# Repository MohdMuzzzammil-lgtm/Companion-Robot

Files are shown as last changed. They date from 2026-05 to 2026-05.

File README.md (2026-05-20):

# 🤖 Companion Robot

An AI-powered autonomous two-wheeled robot that uses a **Samsung smartphone as its brain** — no Raspberry Pi, no expensive hardware. Built for under ₹5000.





---

## 📸 Demo

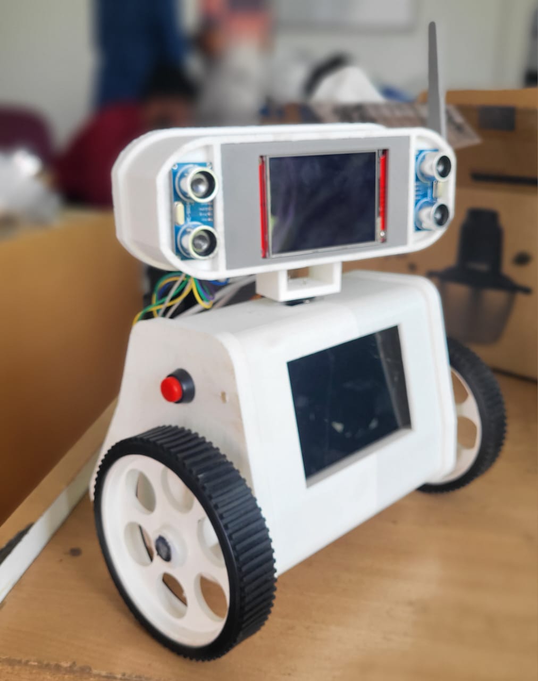
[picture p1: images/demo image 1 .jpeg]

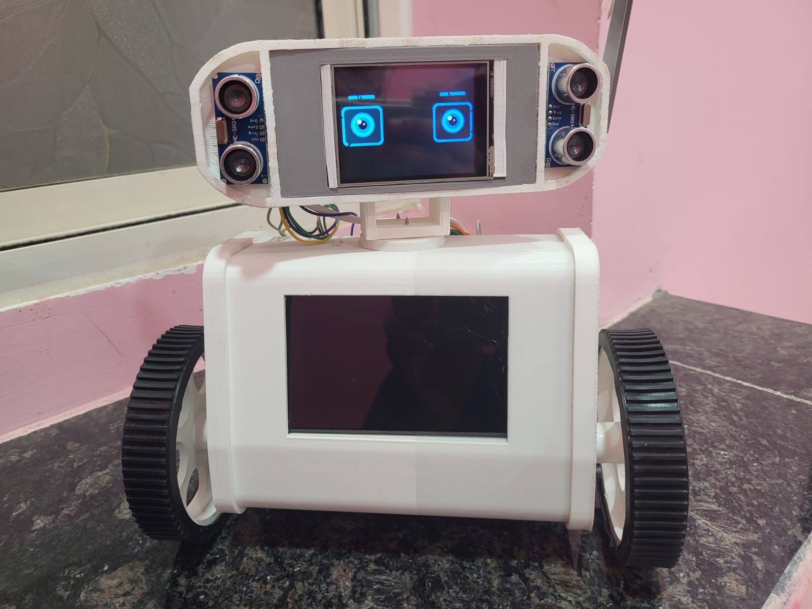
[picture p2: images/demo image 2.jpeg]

Companion Robot
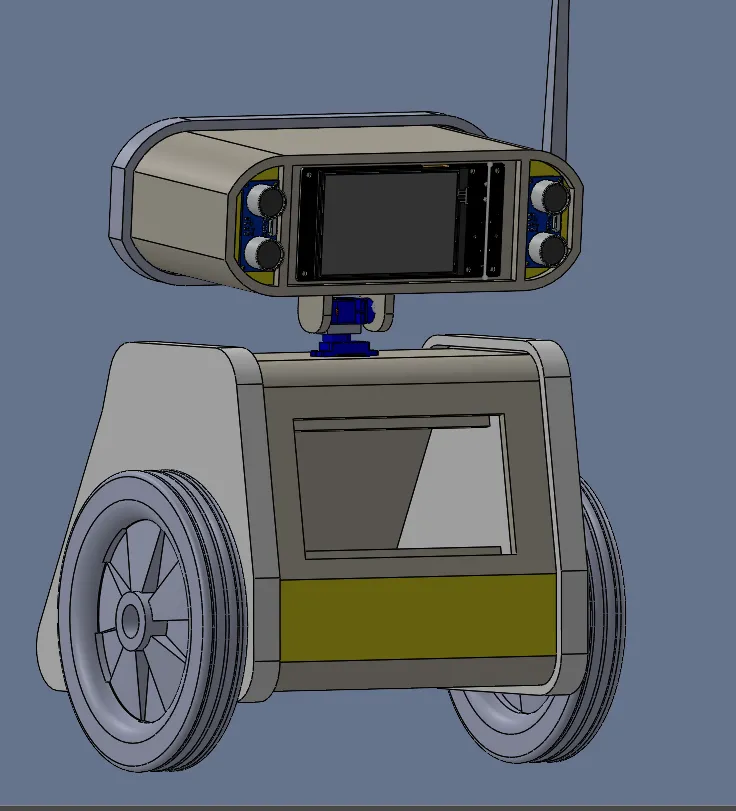
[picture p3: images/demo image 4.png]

---

## ✨ Features

- **Local LLM** — Llama 3.1 via Ollama on laptop GPU, fully offline AI
- **Voice control** — Whisper speech recognition (cloud + local fallback)
- **Animated eyes** — ILI9341 TFT with 5 moods: happy, curious, angry, listening, sleeping
- **Obstacle avoidance** — dual HC-SR04 ultrasonic sensors with pan compensation
- **Human detection** — YOLOv8 on laptop GPU, reacts when it sees a person
- **Expressive antenna** — wiggles when talking, droops when sleeping
- **Gamepad control** — Cosmic Byte Blitz via laptop
- **Touch controller** — HTML joystick interface in phone browser
- **Display mode** — wheels locked for table demos, everything else alive

---

## 🔧 Hardware

| Component | Purpose |
|---|---|
| Samsung S21 FE | AI brain — runs Python + Whisper in Termux |
| ESP32 DevKit v1 (30-pin) | Hardware controller |
| L298N Motor Driver | Controls 2 DC motors |
| 2× Rhino GB37 12V 110RPM | Drive wheels |
| MG996R Servo | Head pan (GPIO 13) |
| SG90 Servo | Antenna wiggle (GPIO 12) |
| 2× HC-SR04 | Obstacle detection |
| ILI9341 2.8" TFT | Animated robot eyes |
| Cosmic Byte Blitz Gamepad | Manual control |
| 2S LiPo 7.4V | Motors + pan servo |
| Power bank 5V | ESP32 + TFT + sensors |

---

## 📌 ESP32 Pin Map

```
GPIO 27 → L298N IN1          GPIO 5  → HC-SR04 Left TRIG
GPIO 26 → L298N IN2          GPIO 34 → HC-SR04 Left ECHO
GPIO 25 → L298N IN3          GPIO 22 → HC-SR04 Right TRIG
GPIO 33 → L298N IN4          GPIO 35 → HC-SR04 Right ECHO
GPIO 13 → MG996R Pan Servo   GPIO 32 → Push Button
GPIO 12 → SG90 Antenna       GPIO 15 → TFT CS
GPIO 23 → TFT MOSI           GPIO 18 → TFT SCK
GPIO 4  → TFT RST            GPIO 2  → TFT DC
```

---

## 🗂️ File Structure

```
companion-robot/
│
├── esp32/
│   └── phonebot_esp32.ino       # ESP32 firmware (Arduino)
│
├── phone/
│   └── robot_brain_v9.py        # Phone brain (Termux Python)
│
├── laptop/
│   ├── phonebot_laptop.py       # Gamepad + YOLOv8 vision
│   └── phonebot_vision.py       # Vision only (older)
│
├── web/
│   ├── phonebot_controller.html # Touch joystick controller
│   └── phonebot_display.html    # Chest status display
│
└── README.md
```

---

## 🚀 Setup

### Prerequisites

**Phone (Termux):**
```bash
pkg install python ffmpeg
pip install requests groq
```

**Laptop:**
```bash
pip install pygame requests ultralytics opencv-python
# Install Ollama: https://ollama.com
ollama pull llama3.1
```

**Arduino IDE** — install these libraries:
- `ESP32Servo`
- `TFT_eSPI`
- `WebServer` (built-in)

### TFT_eSPI User_Setup.h
```cpp
#define ILI9341_DRIVER
#define TFT_MOSI  23
#define TFT_SCLK  18
#define TFT_CS    15
#define TFT_DC     2
#define TFT_RST    4
#define TFT_MISO  -1
#define SPI_FREQUENCY 40000000
```

---

## ⚙️ Configuration

Edit the top of `robot_brain_v9.py` each session:

```python
ESP32_IP   = "X.X.X.X"      # check ESP32 Serial Monitor
LAPTOP_IP  = "X.X.X.X"      # run ipconfig on laptop
GROQ_KEY   = "your_key"      # from console.groq.com (free)
SAFE_DIST  = 40              # obstacle threshold in cm
```

For Ollama to work over WiFi:
```cmd
set OLLAMA_HOST=0.0.0.0:11434
ollama serve
```

---

## 🎮 Startup Checklist

```
1. Turn on phone hotspot (Galaxy S21 / your password)
2. Power ESP32 → note IP from Serial Monitor
3. Connect laptop to hotspot → run ipconfig → note IP
4. Start Ollama: set OLLAMA_HOST=0.0.0.0:11434 && ollama serve
5. Update IPs in robot_brain_v9.py and phonebot_laptop.py
6. Phone Termux:
      termux-wake-lock
      python ~/robot_brain_v9.py
7. Laptop:
      python phonebot_laptop.py
8. Optional touch controller → open in Chrome:
      file:///sdcard/phonebot_controller.html
```

---

## 🗣️ Voice Commands

| Say | Action |
|-----|---|
| *"showcase"* / *"demo"* | Runs table demo routine |
| *"look around"* | Scans environment |
| *"sleep"* / *"goodnight"* | Sleep mode |
| *"wake up"* / *"hello"* | Wake animation |
| *"display mode"* | Lock wheels for table display |
| *"drive mode"* | Unlock wheels |
| *"status"* | Reports AI + STT source |
| Anything else | AI conversation via Llama 3.1 |

---

## 🎮 Gamepad Controls

| Button | Action |
|---|---|
| Left stick | Move |
| Right stick X | Pan head |
| A | Voice mode |
| B | Look around |
| X | Happy mood |
| Y | Toggle vision |
| LB / RB | Speed down / up |
| SELECT | Sleep |
| START | Wake up |

---

## 🌐 ESP32 HTTP API

```
GET /forward         GET /backward        GET /left
GET /right           GET /stop
GET /pan?angle=N     (30–150°)
GET /mood?m=N        (0=happy 1=curious 2=angry 3=listening 4=sleeping)
GET /sensors         returns {"left":N,"right":N,"pan":N}
GET /lookaround      7-angle environment scan
GET /button          returns {"pressed":true/false}
GET /antenna?wiggle=N
GET /displaymode?on=1   lock wheels for table demo
GET /displaymode?on=0   unlock wheels
```

---

## 💡 How It Works

```
[Person speaks] → Phone mic → Whisper STT
                                    ↓
                             Llama 3.1 (Ollama on laptop)
                                    ↓
                    Response → TTS (termux-tts-speak)
                             → ESP32 movement command
                             → Eye mood change

[Camera] → YOLOv8 (laptop) → person detected
                                    ↓
                    Reaction → TTS greeting
                             → Bot turns toward person
                             → Antenna wiggle
```

---

## 🛒 Parts List (India)

| Part | Approx Cost |
|---|---|
| ESP32 DevKit v1 | ₹350 |
| L298N Motor Driver | ₹120 |
| 2× Rhino GB37 Motors | ₹1200 |
| MG996R Servo | ₹200 |
| SG90 Servo | ₹80 |
| 2× HC-SR04 | ₹100 |
| ILI9341 TFT 2.8" | ₹350 |
| 2S LiPo Battery | ₹600 |
| Miscellaneous (wires, standoffs) | ₹300 |
| **Total** | **~₹3300** |

> Samsung S21 FE and laptop not included — reused existing hardware

---

## 📋 Known Issues

- HC-SR04 ECHO pins need `INPUT_PULLUP` (not `INPUT`)
- GPIO 19 conflicts with TFT MISO — Right TRIG moved to GPIO 22
- `termux-tts-speak` must use `Popen` not `run` to avoid timeout
- OTG serial not possible on unrooted Samsung S21 FE
- Ollama must have `OLLAMA_HOST=0.0.0.0:11434` to be reachable over WiFi

---

## 🙏 Acknowledgements

- [Ollama](https://ollama.com) — local LLM serving
- [Groq](https://groq.com) — cloud AI + Whisper fallback
- [Ultralytics YOLOv8](https://github.com/ultralytics/ultralytics) — human detection
- [TFT_eSPI](https://github.com/Bodmer/TFT_eSPI) — ESP32 display library
- [whisper.cpp](https://github.com/ggerganov/whisper.cpp) — local STT fallback

---

## 📄 License

MIT License — free to use, modify, and share.

---

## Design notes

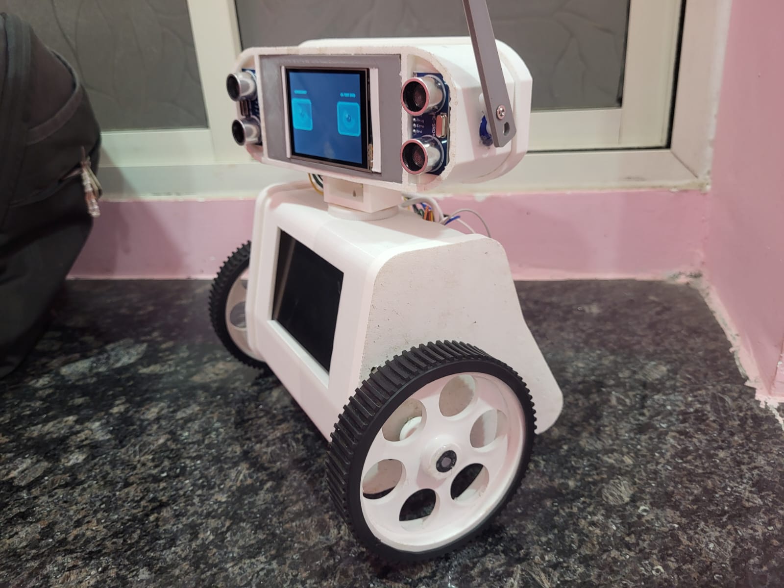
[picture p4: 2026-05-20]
images/demo image 3.jpeg

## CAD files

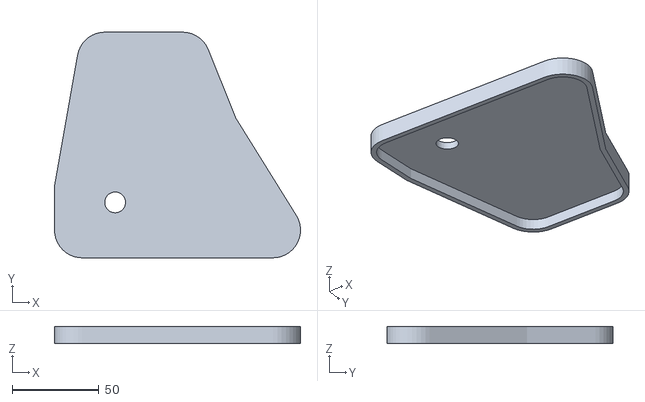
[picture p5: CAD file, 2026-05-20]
3d print stl/side plate 2.STL
142.0 x 130.3 x 10.0

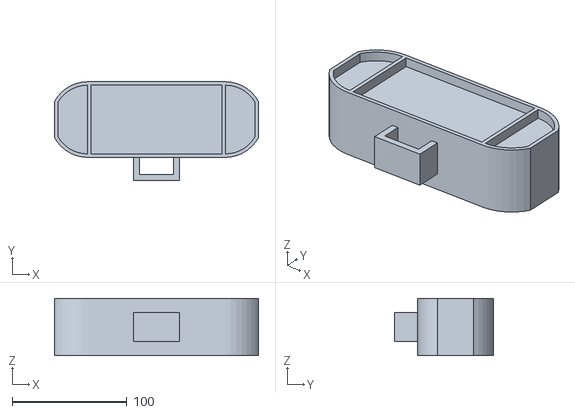
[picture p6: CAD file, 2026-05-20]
3d print stl/head.STL
178.0 x 86.0 x 50.0

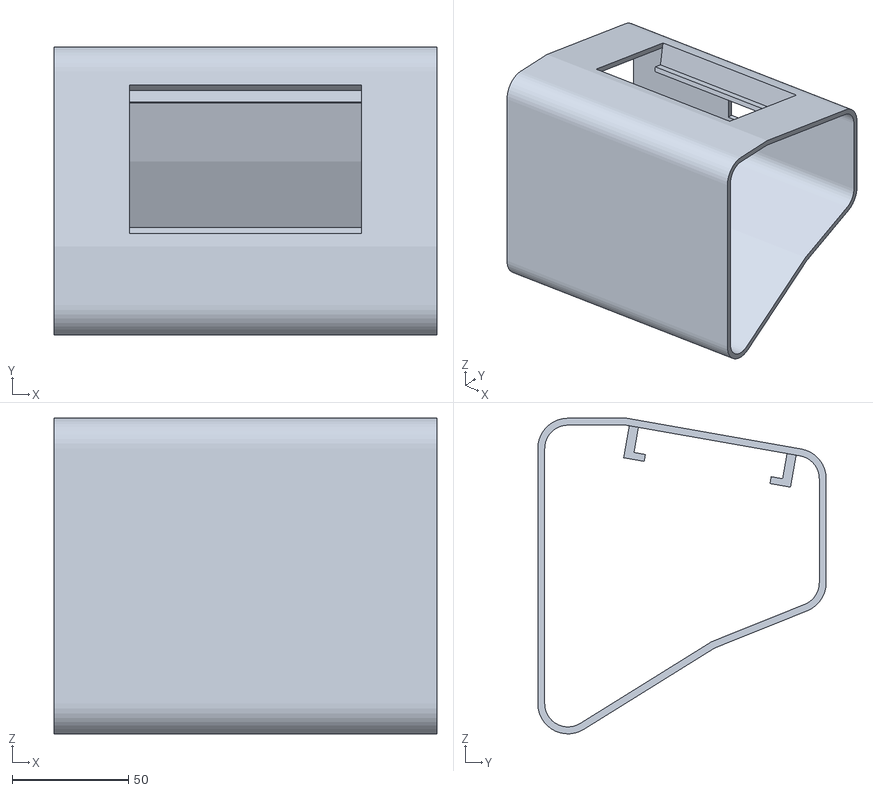
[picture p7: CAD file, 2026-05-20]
3d print stl/mid body.STL
165.0 x 124.3 x 136.0

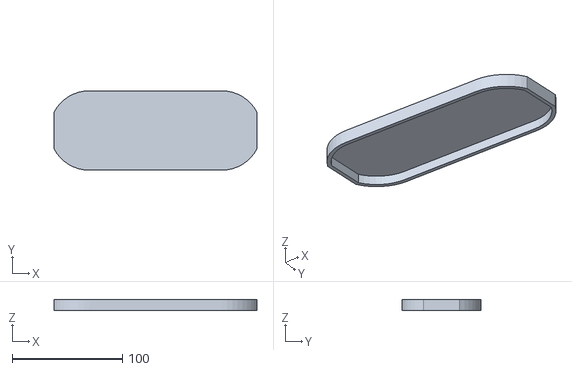
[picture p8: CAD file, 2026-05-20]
3d print stl/head plate.STL
184.0 x 72.0 x 10.0

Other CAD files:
3d print stl/side plate 1.STL

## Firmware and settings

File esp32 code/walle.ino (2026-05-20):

#include <WiFi.h>
#include <WebServer.h>
#include <ESP32Servo.h>
#include <TFT_eSPI.h>
#include <math.h>

// ================================================
//   PHONEBOT ESP32 FIRMWARE v7
//   WALL-E STYLE FACE
//   - Cute rounded eyes with thick frames
//   - Expressive moving eyebrows
//   - Particle sparkles around eyes
//   - Animated dot-grid background
//   - Smooth gaze interpolation
//   - Mood burst animations
// ================================================

const char* ssid     = "wifi name";
const char* password = "wifi password";
WebServer server(80);

// ── Hardware pins ─────────────────────────────────
#define IN1 27
#define IN2 26
#define IN3 25
#define IN4 33
#define PAN_PIN  13
#define TILT_PIN 12
#define TRIG_L  5
#define ECHO_L 34
#define TRIG_R 19
#define ECHO_R 21
#define BTN_PIN 32

Servo panServo;
Servo tiltServo;
TFT_eSPI tft = TFT_eSPI();

// ── Screen ────────────────────────────────────────
#define SW 320
#define SH 240

// ── Eye geometry ──────────────────────────────────
#define EYE_R       52
#define EYE_RIM      7
#define IRIS_R      28
#define PUPIL_R     13
#define L_EX        98
#define R_EX       222
#define EY         125

// ── Eyebrow ───────────────────────────────────────
#define BROW_W      52
#define BROW_H       7
#define BROW_Y_OFF  68

// ── Particles ─────────────────────────────────────
#define MAX_PARTICLES 16
struct Particle {
  float x, y, vx, vy, life;
  uint16_t color;
  bool active;
};
Particle particles[MAX_PARTICLES];

// ── Mood definitions ──────────────────────────────
struct MoodDef {
  uint16_t bgColor;
  uint16_t rimColor;
  uint16_t irisColor;
  uint16_t irisInner;
  uint16_t shineColor;
  uint16_t browColor;
  uint16_t particleCol;
  int      browLift;
  int      browAngleL;
  int      browAngleR;
  float    irisScale;
};

MoodDef moods[] = {
  // bg      rim     iris    inner   shine   brow    particle  lift angL angR  scale
  { 0x0841, 0x4BDF, 0x075F, 0x03BF, 0xFFFF, 0x4BDF, 0x07FF,    0,   0,   0, 1.00 }, // 0 happy    cyan
  { 0x0020, 0x07E0, 0x03C0, 0x0200, 0xFFFF, 0x07E0, 0x07E0,    6,  -8,   8, 1.10 }, // 1 curious  green
  { 0x1800, 0xF800, 0xF000, 0x7800, 0xFFFF, 0xF800, 0xFC00,   -8,  16, -16, 0.85 }, // 2 angry    red
  { 0x1008, 0xF81F, 0xC00F, 0x6007, 0xFFFF, 0xF81F, 0xF81F,    8,  -4,   4, 1.20 }, // 3 listening pink
  { 0x0000, 0x2945, 0x1082, 0x0841, 0x4208, 0x2945, 0x2104,    2,   0,   0, 0.70 }, // 4 sleeping dim
};

// ── State ─────────────────────────────────────────
int   currentMood     = 0;
float gazeX = 0, gazeY = 0;
float gazeXS = 0, gazeYS = 0;   // smoothed
bool  blinking        = false;
unsigned long lastBlink    = 0;
unsigned long lastGaze     = 0;
unsigned long lastParticle = 0;
unsigned long lastBg       = 0;
int   blinkInterval   = 4000;
volatile bool buttonPressed = false;
float dotPhase = 0;

// ================================================
//   MOTOR / SERVO / SENSOR
// ================================================

long getDistance(int trig, int echo) {
  digitalWrite(trig,LOW); delayMicroseconds(2);
  digitalWrite(trig,HIGH); delayMicroseconds(10);
  digitalWrite(trig,LOW);
  long d = pulseIn(echo,HIGH,30000);
  return d==0 ? 999 : d*0.034/2;
}
void stopAll()    { digitalWrite(IN1,0);digitalWrite(IN2,0);digitalWrite(IN3,0);digitalWrite(IN4,0); }
void goForward()  { digitalWrite(IN1,1);digitalWrite(IN2,0);digitalWrite(IN3,1);digitalWrite(IN4,0); }
void goBackward() { digitalWrite(IN1,0);digitalWrite(IN2,1);digitalWrite(IN3,0);digitalWrite(IN4,1); }
void turnLeft()   { digitalWrite(IN1,0);digitalWrite(IN2,1);digitalWrite(IN3,1);digitalWrite(IN4,0); }
void turnRight()  { digitalWrite(IN1,1);digitalWrite(IN2,0);digitalWrite(IN3,0);digitalWrite(IN4,1); }
void movePan(int a)  { panServo.write(constrain(a,30,150)); }
void moveTilt(int a) { tiltServo.write(constrain(a,50,120)); }
void centerHead()    { movePan(90); moveTilt(90); }

void IRAM_ATTR onButtonPress() {
  static unsigned long last=0;
  unsigned long now=millis();
  if(now-last>300){ buttonPressed=true; last=now; }
}

// ================================================
//   PARTICLES
// ================================================

void spawnParticle(float cx, float cy, uint16_t col) {
  for (int i = 0; i < MAX_PARTICLES; i++) {
    if (!particles[i].active) {
      float angle = random(360) * 3.14159 / 180.0;
      float speed = 0.8 + random(100)/100.0 * 1.5;
      particles[i].x     = cx + cos(angle) * (EYE_R + 4);
      particles[i].y     = cy + sin(angle) * (EYE_R + 4);
      particles[i].vx    = cos(angle) * speed;
      particles[i].vy    = sin(angle) * speed - 0.5;
      particles[i].life  = 1.0;
      particles[i].color = col;
      particles[i].active = true;
      break;
    }
  }
}

void spawnBurst(float cx, float cy, uint16_t col, int count) {
  for (int i = 0; i < count; i++) spawnParticle(cx, cy, col);
}

void updateParticles() {
  for (int i = 0; i < MAX_PARTICLES; i++) {
    if (!particles[i].active) continue;
    tft.fillCircle((int)particles[i].x, (int)particles[i].y, 2, TFT_BLACK);
    particles[i].x   += particles[i].vx;
    particles[i].y   += particles[i].vy;
    particles[i].vy  += 0.07;
    particles[i].life -= 0.045;
    if (particles[i].life <= 0) { particles[i].active = false; continue; }
    uint16_t c = particles[i].life > 0.4 ? particles[i].color : 0x4208;
    tft.fillCircle((int)particles[i].x, (int)particles[i].y, 2, c);
  }
}

// ================================================
//   DOT GRID BACKGROUND
// ================================================

void updateDotGrid() {
  dotPhase += 0.09;
  MoodDef& mc = moods[currentMood];
  int spX = SW / 16, spY = SH / 12;
  for (int col = 0; col < 16; col++) {
    for (int row = 0; row < 12; row++) {
      int dx = col * spX + spX/2;
      int dy = row * spY + spY/2;
      float dL = sqrt((float)(dx-L_EX)*(dx-L_EX) + (float)(dy-EY)*(dy-EY));
      float dR = sqrt((float)(dx-R_EX)*(dx-R_EX) + (float)(dy-EY)*(dy-EY));
      if (dL < EYE_R + EYE_RIM + 12 || dR < EYE_R + EYE_RIM + 12) continue;
      float wave = sin(dotPhase + col * 0.45 + row * 0.55);
      tft.fillRect(dx, dy, 1, 1, wave > 0.25 ? mc.bgColor : TFT_BLACK);
    }
  }
}

// ================================================
//   EYEBROW
// ================================================

void drawBrow(int cx, int side, int mood, bool erase) {
  MoodDef& mc = moods[mood];
  int by = EY - BROW_Y_OFF + mc.browLift;
  int innerOff = (side == -1) ? mc.browAngleL : mc.browAngleR;
  int x1 = cx - BROW_W/2;
  int x2 = cx + BROW_W/2;
  int y1 = (side == -1) ? by + innerOff : by - innerOff;
  int y2 = (side == -1) ? by - innerOff : by + innerOff;
  uint16_t col = erase ? TFT_BLACK : mc.browColor;
  for (int t = 0; t < BROW_H; t++) {
    tft.drawLine(x1, y1+t, x2, y2+t, col);
  }
  tft.fillCircle(x1, y1 + BROW_H/2, BROW_H/2, col);
  tft.fillCircle(x2, y2 + BROW_H/2, BROW_H/2, col);
}

void drawBothBrows(int mood, bool erase=false) {
  drawBrow(L_EX, -1, mood, erase);
  drawBrow(R_EX,  1, mood, erase);
}

// ================================================
//   EYE DRAWING — WALL-E STYLE
// ================================================

void drawEye(int cx, int cy, int mood, float gx, float gy, int lidClose) {
  MoodDef& mc = moods[mood];
  float iscale = mc.irisScale;
  int ir = (int)(IRIS_R * iscale);

  // Outer black clear
  tft.fillCircle(cx, cy, EYE_R + EYE_RIM + 3, TFT_BLACK);

  // Thick rim — signature Wall-E look
  tft.fillCircle(cx, cy, EYE_R + EYE_RIM, mc.rimColor);

  // White eyeball
  tft.fillCircle(cx, cy, EYE_R, TFT_WHITE);

  // Iris position with gaze
  int maxG = EYE_R - ir - 5;
  int ix = cx + constrain((int)(gx * maxG), -maxG, maxG);
  int iy = cy + constrain((int)(gy * maxG), -maxG, maxG);

  // Iris layers for depth
  tft.fillCircle(ix, iy, ir + 3, mc.irisInner);
  tft.fillCircle(ix, iy, ir,     mc.irisColor);
  tft.fillCircle(ix, iy, ir - 5, mc.irisInner);

  // Pupil — dilates when listening
  int pr = (mood == 3) ? (int)(PUPIL_R * 1.35) : PUPIL_R;
  tft.fillCircle(ix, iy, pr, TFT_BLACK);

  // Shine dots — Wall-E's cute sparkle
  tft.fillCircle(ix - ir*0.38, iy - ir*0.38, (int)(ir*0.26), mc.shineColor);
  tft.fillCircle(ix + ir*0.15, iy - ir*0.12, (int)(ir*0.12), 0xC618);

  // Sleeping eyelid from bottom
  if (mood == 4) {
    tft.fillRect(cx - EYE_R - 2, (int)(cy + EYE_R*0.08),
                 (EYE_R+2)*2, EYE_R + EYE_RIM + 4, TFT_BLACK);
  }

  // Angry diagonal cut
  if (mood == 2 && lidClose == 0) {
    int cut = (int)(EYE_R * 0.45);
    for (int px = cx - EYE_R; px <= cx + EYE_R; px++) {
      float progress = (float)(px - (cx - EYE_R)) / (EYE_R * 2);
      int cutY = (cx == L_EX)
        ? (cy - EYE_R) + (int)(progress * cut * 1.8)
        : (cy - EYE_R) + (int)((1.0-progress) * cut * 1.8);
      if (cutY > cy - EYE_R)
        tft.drawFastVLine(px, cy - EYE_R - EYE_RIM - 2,
                          cutY - (cy - EYE_R) + EYE_RIM + 2, TFT_BLACK);
    }
  }

  // Blink lid from top
  if (lidClose > 0) {
    tft.fillRect(cx - EYE_R - EYE_RIM - 2,
                 cy - EYE_R - EYE_RIM - 2,
                 (EYE_R + EYE_RIM + 2) * 2,
                 constrain(lidClose, 0, (EYE_R+EYE_RIM)*2+4),
                 TFT_BLACK);
  }

  // Rim highlight arc
  if (mood != 4 && lidClose < EYE_R) {
    for (int a = 205; a <= 335; a += 5) {
      float rad = a * 3.14159 / 180.0;
      tft.drawPixel(
        cx + (int)((EYE_R + EYE_RIM - 2) * cos(rad)),
        cy + (int)((EYE_R + EYE_RIM - 2) * sin(rad)),
        0xFFFF);
    }
  }
}

void drawFace() {
  int lid = blinking ? (EYE_R + EYE_RIM) * 2 : 0;
  drawEye(L_EX, EY, currentMood, gazeXS, gazeYS, lid);
  drawEye(R_EX, EY, currentMood, gazeXS, gazeYS, lid);
  if (!blinking) drawBothBrows(currentMood);
}

void eraseFace() {
  tft.fillCircle(L_EX, EY, EYE_R + EYE_RIM + 4, TFT_BLACK);
  tft.fillCircle(R_EX, EY, EYE_R + EYE_RIM + 4, TFT_BLACK);
  // Erase brow area
  tft.fillRect(L_EX - BROW_W/2 - 8, EY - BROW_Y_OFF - 12, BROW_W+16, BROW_H+20, TFT_BLACK);
  tft.fillRect(R_EX - BROW_W/2 - 8, EY - BROW_Y_OFF - 12, BROW_W+16, BROW_H+20, TFT_BLACK);
}

// ================================================
//   BLINK
// ================================================

void doBlink() {
  for (int l = 0; l <= (EYE_R+EYE_RIM)*2; l += 18) {
    tft.fillCircle(L_EX, EY, EYE_R+EYE_RIM+4, TFT_BLACK);
    tft.fillCircle(R_EX, EY, EYE_R+EYE_RIM+4, TFT_BLACK);
    drawEye(L_EX, EY, currentMood, gazeXS, gazeYS, l);
    drawEye(R_EX, EY, currentMood, gazeXS, gazeYS, l);
    delay(16);
  }
  delay(55);
  for (int l = (EYE_R+EYE_RIM)*2; l >= 0; l -= 18) {
    tft.fillCircle(L_EX, EY, EYE_R+EYE_RIM+4, TFT_BLACK);
    tft.fillCircle(R_EX, EY, EYE_R+EYE_RIM+4, TFT_BLACK);
    drawEye(L_EX, EY, currentMood, gazeXS, gazeYS, l);
    drawEye(R_EX, EY, currentMood, gazeXS, gazeYS, l);
    delay(13);
  }
  drawBothBrows(currentMood);
  if (random(5) == 0) { delay(90); doBlink(); }
}

// ================================================
//   MOOD
// ================================================

void setMood(int mood) {
  int prev = currentMood;
  currentMood = constrain(mood, 0, 4);
  switch(currentMood) {
    case 0: blinkInterval = 4000;  break;
    case 1: blinkInterval = 2000;  break;
    case 2: blinkInterval = 8000;  break;
    case 3: blinkInterval = 10000; break;
    case 4: blinkInterval = 500;   break;
  }
  eraseFace();
  tft.fillScreen(TFT_BLACK);
  if (mood != prev && mood != 4) {
    spawnBurst(L_EX, EY, moods[mood].particleCol, 7);
    spawnBurst(R_EX, EY, moods[mood].particleCol, 7);
  }
  drawFace();
}

// ================================================
//   MAIN ANIMATION
// ================================================

void updateFace() {
  unsigned long now = millis();

  // Smooth gaze
  float px = gazeXS, py = gazeYS;
  gazeXS += (gazeX - gazeXS) * 0.10;
  gazeYS += (gazeY - gazeYS) * 0.10;

  // Redraw iris if moved
  if (abs(gazeXS-px) > 0.008 || abs(gazeYS-py) > 0.008) {
    if (!blinking) {
      tft.fillCircle(L_EX, EY, EYE_R+1, TFT_WHITE);
      tft.fillCircle(R_EX, EY, EYE_R+1, TFT_WHITE);
      drawEye(L_EX, EY, currentMood, gazeXS, gazeYS, 0);
      drawEye(R_EX, EY, currentMood, gazeXS, gazeYS, 0);
    }
  }

  // Random gaze shift
  if (now - lastGaze > 900 + random(2200)) {
    lastGaze = now;
    if (currentMood != 4) {
      gazeX = (random(200)-100)/100.0 * 0.65;
      gazeY = (random(160)-80) /100.0 * 0.55;
    }
  }

  // Blink
  if (now - lastBlink > (unsigned long)(blinkInterval + random(2500))) {
    lastBlink = now;
    if (currentMood != 4) {
      doBlink();
    } else {
      // Sleeping flutter
      drawEye(L_EX, EY, currentMood, 0, 0, 4);
      drawEye(R_EX, EY, currentMood, 0, 0, 4);
      delay(70);
      drawEye(L_EX, EY, currentMood, 0, 0, 0);
      drawEye(R_EX, EY, currentMood, 0, 0, 0);
    }
  }

  // Particles — occasional sparkle around eyes
  if (now - lastParticle > 380 && currentMood != 4 && random(3)==0) {
    lastParticle = now;
    spawnParticle(L_EX, EY, moods[currentMood].particleCol);
    spawnParticle(R_EX, EY, moods[currentMood].particleCol);
  }
  updateParticles();

  // Background dot grid
  if (now - lastBg > 110) {
    lastBg = now;
    updateDotGrid();
  }
}

// ================================================
//   HTTP ROUTES
// ================================================

void setupRoutes() {
  server.on("/", [](){ server.send(200,"text/plain","PhoneBot V7!"); });
  server.on("/forward",  [](){ goForward();  server.send(200,"text/plain","ok"); delay(500); stopAll(); });
  server.on("/backward", [](){ goBackward(); server.send(200,"text/plain","ok"); delay(500); stopAll(); });
  server.on("/left",     [](){ turnLeft();   server.send(200,"text/plain","ok"); delay(350); stopAll(); });
  server.on("/right",    [](){ turnRight();  server.send(200,"text/plain","ok"); delay(350); stopAll(); });
  server.on("/stop",     [](){ stopAll();    server.send(200,"text/plain","ok"); });
  server.on("/pan",  [](){ if(server.hasArg("angle")) movePan(server.arg("angle").toInt());  server.send(200,"text/plain","ok"); });
  server.on("/tilt", [](){ if(server.hasArg("angle")) moveTilt(server.arg("angle").toInt()); server.send(200,"text/plain","ok"); });
  server.on("/centerhead", [](){ centerHead(); server.send(200,"text/plain","ok"); });
  server.on("/lookaround", [](){
    movePan(55); delay(400); movePan(125); delay(400);
    movePan(90); delay(200); moveTilt(70); delay(300); moveTilt(90);
    server.send(200,"text/plain","ok");
  });
  server.on("/sensors", [](){
    long dL=getDistance(TRIG_L,ECHO_L);
    long dR=getDistance(TRIG_R,ECHO_R);
    server.send(200,"application/json",
      "{\"left\":"+String(dL)+",\"right\":"+String(dR)+"}");
  });
  server.on("/button", [](){
    if(buttonPressed){ buttonPressed=false;
      server.send(200,"application/json","{\"pressed\":true}"); }
    else server.send(200,"application/json","{\"pressed\":false}");
  });
  server.on("/mood", [](){
    if(server.hasArg("m")) setMood(server.arg("m").toInt());
    server.send(200,"text/plain",String(currentMood));
  });
  server.on("/look", [](){
    if(server.hasArg("x")) gazeX = server.arg("x").toInt()/100.0;
    if(server.hasArg("y")) gazeY = server.arg("y").toInt()/100.0;
    server.send(200,"text/plain","ok");
  });
}

// ================================================
//   SETUP
// ================================================

void setup() {
  Serial.begin(115200);
  Serial.println("\n=== PhoneBot V7 Booting ===");

  pinMode(IN1,OUTPUT); pinMode(IN2,OUTPUT);
  pinMode(IN3,OUTPUT); pinMode(IN4,OUTPUT);
  stopAll();
  pinMode(TRIG_L,OUTPUT); pinMode(ECHO_L,INPUT);
  pinMode(TRIG_R,OUTPUT); pinMode(ECHO_R,INPUT);
  panServo.attach(PAN_PIN);
  tiltServo.attach(TILT_PIN);
  centerHead();
  pinMode(BTN_PIN,INPUT_PULLUP);
  attachInterrupt(digitalPinToInterrupt(BTN_PIN),onButtonPress,FALLING);

  tft.init();
  tft.setRotation(3);
  tft.fillScreen(TFT_BLACK);

  for (int i = 0; i < MAX_PARTICLES; i++) particles[i].active = false;

  // ── Boot animation ─────────────────────────────
  currentMood = 0;
  gazeX = gazeY = gazeXS = gazeYS = 0;

  // Eyes grow from center dot
  for (int r = 2; r <= EYE_R + EYE_RIM; r += 4) {
    tft.fillCircle(L_EX, EY, r, moods[0].rimColor);
    tft.fillCircle(R_EX, EY, r, moods[0].rimColor);
    delay(15);
  }
  delay(180);

  // Eyes open — lid rises
  for (int l = (EYE_R+EYE_RIM)*2; l >= 0; l -= 12) {
    tft.fillCircle(L_EX, EY, EYE_R+EYE_RIM+4, TFT_BLACK);
    tft.fillCircle(R_EX, EY, EYE_R+EYE_RIM+4, TFT_BLACK);
    drawEye(L_EX, EY, 0, 0, 0, l);
    drawEye(R_EX, EY, 0, 0, 0, l);
    delay(18);
  }
  drawBothBrows(0);

  // Particle burst on wake!
  spawnBurst(L_EX, EY, moods[0].particleCol, 10);
  spawnBurst(R_EX, EY, moods[0].particleCol, 10);
  for (int i = 0; i < 25; i++) { updateParticles(); delay(25); }

  // Curious look-around like Wall-E waking up
  gazeX=-0.8; delay(280);
  gazeX= 0.8; delay(280);
  gazeX=0; gazeY=-0.5; delay(200);
  gazeX=0; gazeY=0;

  // WiFi — blink while connecting
  WiFi.begin(ssid, password);
  Serial.print("Connecting");
  while (WiFi.status() != WL_CONNECTED) {
    delay(350); Serial.print(".");
    doBlink();
  }
  Serial.println("\n✓ http://" + WiFi.localIP().toString());

  // Happy burst on connected!
  spawnBurst(L_EX, EY, moods[0].particleCol, 12);
  spawnBurst(R_EX, EY, moods[0].particleCol, 12);

  setupRoutes();
  server.begin();
  Serial.println("=== PhoneBot V7 Ready! ===");
}

void loop() {
  server.handleClient();
  updateFace();
}
